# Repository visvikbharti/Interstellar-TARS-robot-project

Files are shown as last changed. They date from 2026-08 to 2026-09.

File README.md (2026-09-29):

# TARS — Mini Walking Robot (Interstellar)

A ~25–30cm, 3D-printed, walking and talking replica of TARS from *Interstellar*.
Raspberry Pi brain, servo-driven gait, Claude-powered personality with the
movie's adjustable **humor** and **honesty** settings.

> Cooper: "Hey TARS, what's your honesty parameter?"
> TARS: "Ninety percent."

## Project layout

```
software/    TARS's brain — personality, chat, (soon) voice + servo control
hardware/    Bill of materials, parametric CAD and its drawing, print plan (wiring doc to come)
docs/        Design decisions, research notes, India sourcing report
```

## Quick start (talk to TARS today, no hardware needed)

```sh
cd software
python3 -m venv .venv && source .venv/bin/activate
pip install -r requirements.txt
export ANTHROPIC_API_KEY=sk-ant-...   # or `ant auth login`
python -m tars.cli
```

Then chat:

```
You: /humor 100
TARS: Confirmed. Humor, 100 percent.
You: what are our odds of finishing this robot?
```

Without an API key it runs in offline mode with canned TARS quips, so you can
test the CLI immediately.

## Build status

- [x] Personality core (humor/honesty settings, Claude-powered chat, CLI)
- [x] Parametric CAD (`hardware/cad/tars.scad`, OpenSCAD, v0.3.1) and a dimensioned
      drawing read from it (`python hardware/drawing.py` -> `hardware/tars_drawing.png`)
- [x] Physics simulation — **it walks, robustly.** The build-target V3
      lift-and-swing gait, reworked into a crutch vault on 29 Sep 2026,
      walks 36 cm in 15 s (2.4 cm/s) at true MG996R torque and stays upright
      at every solver setting tested (`python v3_sim.py --robust`: time steps
      2 to 0.25 ms, three integrators, both friction cones, floor friction
      0.5-1.3, 20% weaker servos, body mass -10%/+20%). The IMU-balance walker
      and wheel mode do not work yet (`simulation/README.md`)
- [x] Research: proven community design identified (TARS-AI V3, 25.0cm,
      CC-BY-NC) — see `docs/research-notes.md`
- [ ] Parts ordered (`hardware/BOM.md`; prices live-verified 10 Aug 2026 — ready to order)
- [ ] Chassis printed (outsourced — `hardware/print-plan.md`)
- [ ] Voice: wake word → speech-to-text → TARS → text-to-speech
- [ ] Walking gait on real hardware
- [ ] Final assembly: it walks, it talks, it judges your plans

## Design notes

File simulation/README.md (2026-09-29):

# TARS simulations (MuJoCo)

Three models, all sharing dimensions with `hardware/cad/tars.scad`:

| Files | What it tests | Result (audited 2026-09-29) |
|---|---|---|
| `v3_model.py` + `v3_sim.py` | **The build architecture** (TARS-AI V3): central body touches ground, legs lift+swing. No balancing, no IMU | **walks 36 cm in 15 s (2.4 cm/s), upright**, with the crutch-vault gait, and the same at every setting in `--robust` |
| `gen_model.py` + `gait_sim.py` | v1 custom idea: 2 servo pairs + MPU6050 IMU balance ("lean and catch") | **does not walk upright**: slumps into a tilted A-frame within 0.5 s (0/75 sweep settings upright) |
| `pinwheel_model.py` + `roll_sim.py` | **Miller's planet WHEEL MODE**: 4 slabs splayed into a rimless wheel | **does not roll**: tumbles ~0.4 m, then folds flat or falls sideways; needs a different mechanism (telescoping spokes, TARS3D) -> v2 research |

```sh
source software/.venv/bin/activate    # from the project root
cd simulation
python v3_model.py && python v3_sim.py          # the build gait (headless)
python v3_sim.py --robust                       # the same gait across 15 solver/physics settings
mjpython v3_sim.py --gui                        # watch the V3 walk
python pinwheel_model.py && mjpython roll_sim.py --gui   # wheel mode (falls: v2 research)
mjpython gait_sim.py --gui                      # the IMU-balance walker (slumps)
```

Every sim has `--sweep` for parameter search and runs until you close the
window in `--gui` mode (auto-reset on falls, camera tracks the robot).
`v3_sim.py --sweep` only keeps gaits that stay upright at 2 ms AND at 0.5 ms
with elliptic friction cones. Every fall test checks the body and all slabs
(within 45 deg of vertical) and the axle height, not just the torso.
`/Applications/MuJoCo.app` opens any of the `tars*.xml` files interactively.

## Findings log

1. Open-loop wiggling on sharp-edged feet falls, always (300+ configs).
2. Rounded bottom edges (flat middle + 6mm round-over) let the robot roll
   over the stance foot; mass must sit LOW and CENTERED.
3. Two ways to walk: IMU balance loop (fewer servos, dynamic) or the V3
   lift+swing with ground-resting body (more servos, unconditionally stable).
   We build V3 first; the gait keyframes port straight to the Pi.
4. V3 gait: feet plant slightly AHEAD (the body vaults forward over them),
   small lift (30%), vault overlapped with lowering — a controlled forward
   topple. step=14deg back=4deg tempo=0.6 lift=0.3 -> 2.0cm/cycle.
5. Wheel mode physics: a 4-spoke rimless wheel cannot start from rest
   (90-degree tip-overs) — it must be THROWN in at >=1.6 m/s, and from a
   1.8 m/s entry coasts ~1.6m. Just like the movie. Powered rolling = v2
   research (telescoping spokes or 8+ spokes).
6. **Audit, 29 Sep 2026.** Re-running every sim with finer solver settings and
   stricter fall tests: (a) the old V3 gait (feet planted 14 deg ahead, vault
   overlapped with lowering) only walked at the default 2 ms time step; at
   0.5 ms, with the implicit integrator or with elliptic friction cones it
   tipped over within 3-9 s. Its progress came from the body rocking on its
   rails, not from a vault: the body landed before it vaulted. (b) The
   IMU-balance walker's "upright" came from a fall test that only checked the
   torso; its slabs slump to ~60 deg within 0.5 s. (c) Wheel mode's "~1.6 m"
   was the folded, flat robot creeping undriven after a ~0.4 m tumble.
7. **The fix: a crutch vault.** Press the legs down while they are VERTICAL
   (the weight stays over the feet), rotate the hinges back 12 deg with the
   body fully off the ground (it swings forward over the planted feet), set
   it down, then swing the unloaded legs forward. vault=12 lift=0.7
   tempo=1.0 -> 35.9 cm in 15 s (4.3 cm/cycle), worst tilt 11.5 deg, the same
   to within 2 mm at every time step from 2 ms to 0.25 ms. Peak swing torque
   0.30 N m (30% of an MG996R), peak lift force ~11 N (of 55 N).

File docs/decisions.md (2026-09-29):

# Design Decisions

## 1. Brain: Raspberry Pi 5, 8GB  (decided 2026-08-10)

The user owns NO Raspberry Pi; buying new in India (New Delhi).

**Choice: Raspberry Pi 5 — 8GB.** Rationale:
- The voice pipeline (wake word + on-device speech-to-text via sherpa-onnx +
  Piper text-to-speech) runs comfortably in real time on a Pi 5; on a Pi 4 the
  speech-to-text step is noticeably laggy for conversation.
- 8GB gives headroom to run STT + TTS + servo control + the Claude client
  simultaneously without swap. The 4GB saves ₹7,370 (live-verified 10 Aug 2026
  — India Pi pricing is steep, so the delta is real money), but on-device
  STT/TTS is exactly what eats RAM, and the only in-stock 4GB source is the
  vendor the BOM cautions against for large orders. 8GB stands.
- The community TARS-AI stack targets Pi 5, so we stay on the well-trodden path.
- The LLM itself is *not* local — TARS thinks via the Claude API — so we don't
  need anything bigger (no Jetson etc.).

Buy alongside it: official 27W USB-C PSU (bench use), the official Active
Cooler (the Pi 5 throttles without it), 64GB microSD (no India hobby vendor
stocks A2 — the BOM's SanDisk Ultra A1 is fine for a robot). On the robot, the
Pi runs from the battery through a 2S-rated 5V/5A converter instead of the PSU.
Exact INR prices + vendors: see `hardware/BOM.md` (live-verified 10 Aug 2026).

## 2. CAD: OpenSCAD  (user-suggested; agreed)

- Fully parametric — every dimension in `hardware/cad/tars.scad` is a variable;
  change `leg_h` once and the whole robot rescales.
- Text-based → diffs cleanly in git, and we can co-edit it easily.
- Exports STL directly for slicing AND meshes/dimensions shared with the
  simulator (`simulation/gen_model.py` / `v3_model.py` mirror the same
  numbers into MuJoCo MJCF).
- Escape hatch: if we later adopt proven community STLs (Charlie Diaz /
  TARS-AI, license research pending), OpenSCAD still handles our custom parts
  (spine, mounts, brackets).

## 3. Simulation: MuJoCo  (instead of Cinema 4D)

"Cinema 4D" is an animation/rendering tool — it makes pretty pictures but does
not simulate physics, motors, friction, or falling over, which is what we need
before printing. The plan:

| Purpose | Tool | Why |
|---|---|---|
| Gait physics (does it walk? fall?) | **MuJoCo** | DeepMind's physics engine, the robotics-research standard; installs instantly from a wheel; scriptable in Python; `mjpython gait_sim.py --gui` gives a live 3D view on the Mac |
| Mechanical fit / printability | **OpenSCAD** previews + slicer | Wall thickness, clearances, print orientation |
| Pretty renders (later, optional) | Blender (free) | Same niche as Cinema 4D, no license cost |

Alternatives considered: PyBullet (first pick, but it compiles from source on
macOS and the build failed — MuJoCo ships wheels and is the better engine
anyway), Webots (good fallback for sensor simulation), Gazebo (ROS-oriented,
overkill).

Big win: the balance gains and gait constants we tune in MuJoCo port almost
directly to the real servo code on the Pi.

## 4. Gait mechanism — VALIDATED IN SIM (2026-08-10)

> **Superseded by §8 (audit, 2026-09-29):** the IMU-balance result below did
> not hold up; the walker slumps into a tilted A-frame. Kept for the record.

Simulation verdict on the v0.1 two-servo rocking gait: **open-loop always falls**
(300+ configs swept). What made it walk:
- Deeper slabs (55mm), rounded bottom edges (roll-over, not edge-pivot)
- Low, centered mass: 18650 cells in outer slab bottoms, Pi on a front chest plate
- **IMU balance loop** (MPU6050): stance legs correct torso pitch, segway-style
- "Lean and catch": 0.04 rad forward lean + 25° kick gait at 1.2 Hz
- Result: **30cm in 10s (3.0 cm/s), upright, drift <1cm** at true MG996R
  torque (1.0 N·m; an earlier 5.1 cm/s figure came from an inflated 2.5 N·m
  servo model — corrected in the 10 Aug audit, all 75 sweep configs still
  stay upright)

## 5. Chassis fork: TARS-AI V3 STLs vs our custom SCAD

Research verdict: TARS-AI Community V3 is the ONLY proven walkable open design
(25.0cm tall — measured from their CAD; CC-BY-NC 4.0, personal use fine). Its
gait needs no balancing: 2 lift + 2 swing servos, torso rests on the ground
between steps.

**Recommended plan:** print & build TARS-AI V3 first (proven path: STLs,
assembly wiki, calibration tool, community Discord) while continuing our custom
OpenSCAD + MuJoCo design as the v2 platform (fewer servos, dynamic balance, our
own look). The electronics BOM is ~identical for both, so nothing ordered is
wasted either way. Next sim milestone: model the V3 lift+swing morphology in
MuJoCo and reproduce their keyframe gait before hardware arrives.

## 6. Sim-validated architecture + wheel mode (2026-08-10, late session)

> **Superseded by §8 (audit, 2026-09-29):** the V3 gait below only walked at
> the default 2 ms time step, and wheel mode did not roll. Kept for the record.

- **V3 morphology simulated and walking**: body-on-ground + lift/swing legs,
  2.4 cm/s quasi-static, zero falls (at true 1.0 N·m servo torque). Winning
  gait: plant feet 14deg AHEAD (step=14, back=4 — the body vaults forward
  over them), lift 30% of 35mm travel, vault overlapped with lowering
  (controlled forward topple). These keyframes ARE the future Pi servo code.
- **Wheel mode (Miller's planet)**: works as kickstart-and-coast — needs a
  ≥1.6 m/s entry; at 1.8 m/s (the sweet spot — 2.0 falls) the 4-slab
  pinwheel cartwheels ~1.6m. Cannot start from rest
  (4 spokes = 90deg tip-overs) and powered pumping destabilizes via hub
  counter-spin. Sustained powered rolling needs per-slab continuous drive +
  telescoping spokes (TARS3D, arXiv 2510.05001) -> v2 hardware goal with
  serial-bus servos.
- **CAD v0.3 final for v1**: central chassis (twin-slab facade; Pi vertical,
  display window, speaker grille, servo bays at the axle) + two outer legs
  (35mm axle slot for lift travel, 608ZZ bearing seat). v0.4 details pending:
  lift crank linkage, lids, wire channels.

## 7. Printing: outsourced to a print service (2026-08-10)

No home printer — chassis parts are ordered from an online 3D-printing
service, the workflow proven the same week on the micro-quad project
(ZBOTiC order delivered 10 Aug 2026; received part matched CAD, press-fit
bores true). Consequences:
- No filament spools in the BOM — material is specified in the print order
  instead (black PLA cosmetic, black PETG 3+ walls for load parts).
- No printer/bed-size constraint on our side.
- Vendors, settings, pinned STL source and on-receipt checks:
  `hardware/print-plan.md`.

## 8. Simulation audit + crutch-vault gait (2026-09-29)

Re-ran every simulation with finer solver settings (0.5 and 0.25 ms time
steps, the implicit and RK4 integrators, elliptic friction cones) and with a
strict fall test (body AND every slab within 45 deg of vertical, axle above
150 mm). Findings:

- **Old V3 gait** (feet planted 14 deg ahead, vault overlapped with lowering):
  walked only at the default 2 ms step; tipped over within 3-9 s at 0.5 ms,
  with implicitfast, or with elliptic cones. The body landed before it could
  vault; the progress came from rocking on the rails.
- **IMU-balance walker:** slumps into a tilted A-frame within 0.5 s (slabs
  ~60 deg, axle 140 mm). The old test only checked the torso.
- **Wheel mode:** tumbles ~0.4 m, then folds flat or falls sideways. Stiffer
  spokes (5-20 N m) fall sideways sooner. Needs a different mechanism (v2).

**Decision:** the build gait is now a **crutch vault**: press down on
vertical legs (weight over the feet), rotate the hinges back 12 deg with the
body fully off the ground, set down, swing the unloaded legs forward.
`vault=12 lift=0.7 tempo=1.0`: 35.9 cm in 15 s, worst tilt 11.5 deg, and the
same result at all 15 settings in `python v3_sim.py --robust` (incl. floor
friction 0.5-1.3, 20% weaker servos, body mass -10%/+20%). Peak loads: swing
0.30 N m (MG996R ~1.0), lift ~11 N (of 55). These keyframes are the future
Pi servo code. The CAD needs no change (the gait uses 24.5 of the 35 mm lift
travel).

## 9. CAD v0.3.1: the lift slot moves to the body (2026-09-29)

Drawing the chassis up (`hardware/drawing.py`) and cutting sections through
`tars.scad` turned up four problems in v0.3, all fixed in v0.3.1:

- **The lift could not work.** The 35 mm slot was in the legs with the axle at
  its top at rest, so a leg could only rise relative to the axle, never press
  down (the gait needs the legs to push the body up). The slot is now in the
  body: at rest the body sits on the ground with the axle at the top of the
  slot, and pressing the legs down raises the body up to 35 mm. This is the
  relative motion `v3_model.py` already simulates, so the gait results stand.
  Legs keep a round axle bore and a round 608ZZ seat (the swing).
- **The right leg was not mirrored**, so its bearing seat faced outwards. Both
  seats now face the body (`print_leg_right` prints the mirrored leg).
- **The left servo bay sat in the middle of the body** (its offset ignored the
  side). The bays are now mirror images, one against each inner wall.
- **The face panels were turned 90 deg and half a panel low**, so they
  overlapped and ran off the legs. They are now the 3 rows of
  (h - 40)/3 - 6 by w - 12 the formula describes.

The drawing reads every dimension from `tars.scad`, so it cannot drift from
the model.

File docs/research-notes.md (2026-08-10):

# Research Notes — TARS builds landscape (2026-08-10)

Digest of a 10-agent research sweep (5 topics + critic + 4 follow-ups), all
claims verified on fetched pages. Full raw report archived in the session.

## The one proven base: TARS-AI Community V3

- **github.com/TARS-AI-Community/TARS-AI** — 574★, active (last push Apr 2026),
  the de-facto continuation of Charlie Diaz's original design. Default branch
  is **V3** (do NOT use `main` — it carries obsolete V1/V2 tooling).
- **Exactly 25.0cm tall** (an agent downloaded their official STEP assembly and
  measured it: 241.8 × 250.1 × 65.4 mm). Print at 100% — do not rescale, every
  fit is dimensioned around COTS parts.
- ~130 pre-oriented STLs, full BOM, assembly wiki. License **CC-BY-NC 4.0**:
  personal building/modifying is explicitly fine (attribution: Charlie Diaz /
  TARS-AI Community / AtomikSpace); selling prints is not.
- Survey verdict: **no alternative walkable STL set exists anywhere** —
  everything else is static display models, closed research (TARS3D), or
  software stacks reusing this same chassis.

## How the proven design walks (important!)

V3 uses **4 servos**: left/right torso-LIFT + left/right leg-SWING. The gait
never balances — it lifts the torso, swings legs, and **rests the torso on the
ground** while repositioning. Quasi-static keyframe tables (percent coords in
`module_movements.py`), tuned via config.ini PWM endpoints + offsets.
Calibration: official video "Getting TARS Moving Right" (youtube We_4mcOO7hI)
by the V3 hardware author + `app-servotester.py` (GUI/terminal). Calibrate
DURING assembly (preset servos before pressing horns on, never rotate a powered
servo by hand). Our MuJoCo sim independently confirmed *why* the lift DOF
exists: without it, an open-loop 2-servo gait always tips over — we made
2-servo walking work only by adding an IMU balance loop.

## Voice stack (2026 state of the art on Pi)

| Layer | Choice | Notes |
|---|---|---|
| Wake word | openWakeWord, custom "Hey TARS" (or TARS-AI's Atomik) | Train free in Colab from synthetic speech, <1h |
| STT | sherpa-onnx (TARS-AI default) or Moonshine (MIT, 237ms on Pi 5) | Fully local on Pi 5 |
| TTS | Piper (local, free; now OHF-Voice/piper1-gpl) | ElevenLabs voice-clone of the movie voice is the community method for authenticity (~$6/mo; ToS caveat — cloning an actor's voice) |
| LLM | **Claude API** (our personality core) | Precedent: "Claudia" project runs Claude on a Pi Zero 2 W, <2s end-to-end. TARS-AI's backends are OpenAI-compatible → we write a thin adapter or our own ~200-line loop |

**The latency law**: stream the LLM reply and speak sentence-by-sentence
(start TTS after the first sentence). This is what turns 8–15s perceived
latency into ~2s. Design target: wake→speech ≈ 1.5–4s.

## Pi 4 vs Pi 5 (contradiction resolved by reading their code)

The wiki documents only Pi 5, but `Install.sh` + `module_config.py` on V3 have
a first-class **Pi 4 profile** (local STT/TTS/wake word all allowed; loses
camera vision, face/emotion, half the STT threads, 8k vs 16k context). Pi 3 /
Zero 2 = cloud-only mode. → For a new purchase, Pi 5 8GB is the clear choice.

## Audio amp question (resolved for stock V3 — our BOM deviates)

The **TARS-AI V3 stock BOM's** Waveshare USB audio dongle has an **onboard
2.6W amplifier** driving the speaker directly — if you build stock V3 audio,
no MAX98357A is needed (if quiet: internal trim screw + alsamixer). **Our**
`hardware/BOM.md` instead buys the I2S pair (INMP441 mic + MAX98357A amp):
better audio quality and no USB dongle, but it deviates from the stock V3
software path and needs I2S dtoverlay config on the Pi. Both paths work —
just know which one you're wiring.

## Key pitfalls from the Diaz lineage

- Diaz's V1 broke printed drivetrain parts after ~4 steps — heavy batteries +
  torso-heavy mass. Keep mass low and light; PETG 3+ walls on load parts.
- Route arm servo cables through the torso during initial assembly even if
  arms come later (otherwise: full disassembly).
- Gentler gait = pull in the lift endpoints in config.ini, not new phase tables.
- Support runs on Discord (discord.gg/AmE2Gv9EUt); GitHub issues are locked.

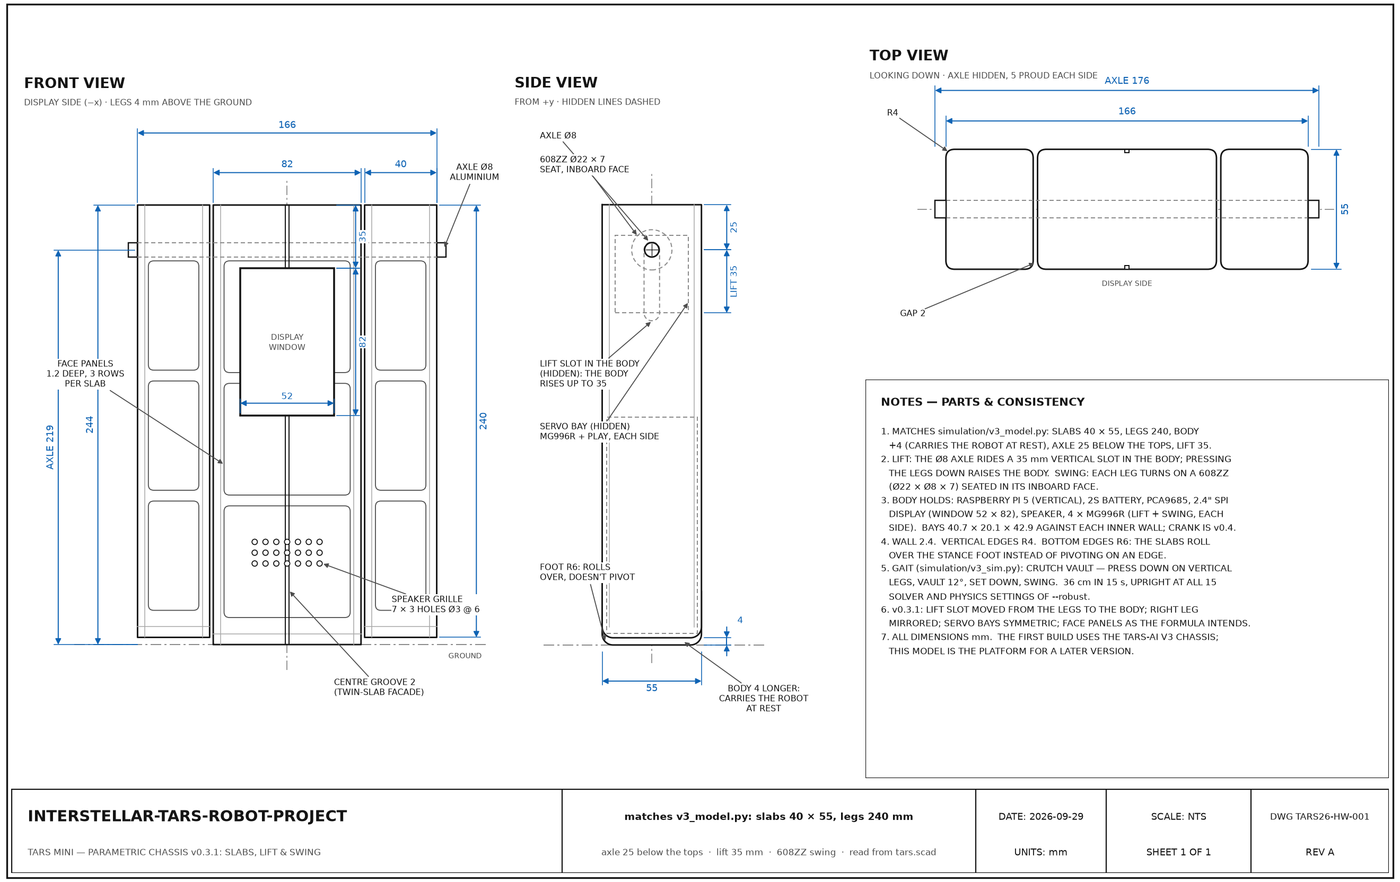
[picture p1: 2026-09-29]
hardware/tars_drawing.png

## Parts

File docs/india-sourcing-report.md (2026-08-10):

# Robot Parts Sourcing — India (New Delhi buyer), August 2026

**Method note:** every price below was pulled from the vendor's own live storefront data (robu.in product/listing pages rendered through a reader proxy; Shopify storefront product API for Robocraze / ThinkRobotics / KitsGuru / The Engineer Store), not from search snippets. robu.in prices are the "(Incl. GST)" figure shown on the page. Shopify vendors display final cart price. Prices verified 10 Aug 2026.

## Master table

| Item | Spec | Price (INR) | Vendor + URL | Notes (stock / alternatives) |
|---|---|---|---|---|
| **Raspberry Pi 5 8GB** | BCM2712, 8GB | **19,999** | [robu.in](https://robu.in/product/raspberry-pi-5-model-8gb/) SKU 1749034 | **In Stock.** Best reliable price. |
| Pi 5 8GB (alt) | same | 19,849.99 | [ThinkRobotics](https://thinkrobotics.com/products/raspberry-pi-5) | In stock (8GB variant). Effectively tied with robu. |
| Pi 5 8GB (alt) | same | 22,339 | [Robocraze](https://robocraze.com/products/raspberry-pi-5-8gb) | In stock but ~₹2,340 more. |
| Pi 5 8GB (cheapest, **caution**) | same | 17,967 | [The Engineer Store](https://www.theengineerstore.in/products/raspberry-pi-5-8gb) | Listed "52% off ₹37,100" (inflated MRP) and page warns *"Quantity selected exceeds current stock"*. Verify before relying on it. |
| **Pi 5 4GB** | BCM2712, 4GB | 12,631 | [The Engineer Store](https://www.theengineerstore.in/products/raspberry-pi-5-4gb) | Available. ThinkRobotics 4GB = ₹13,609.99 but **out of stock**. |
| Pi 5 2GB | budget path | 7,799.99 | [ThinkRobotics](https://thinkrobotics.com/products/raspberry-pi-5) | In stock — this is the "₹7-8k Pi 5" you see quoted online; it is the 2GB, not 8GB. |
| **Official 27W USB-C PD PSU** | 5.1V/5A, **IN plug**, black or white | **1,255** | [robu.in black](https://robu.in/product/official-27w-usb-c-pd-power-supply-for-raspberry-pi-5-black/) / [white](https://robu.in/product/official-27w-usb-c-pd-power-supply-for-raspberry-pi-5-white/) | **In Stock**, both colours. Robocraze ₹1,204 but **out of stock**; ThinkRobotics ₹1,479.99 **out of stock**; Engineer Store ₹1,649.89 available. |
| **Official Pi 5 Active Cooler** | clip-on PWM fan+heatsink | **488** | [robu.in](https://robu.in/product/official-raspberry-pi-5-active-cooler/) SKU 1749017 | **In Stock**, cheapest. Robocraze ₹529 out of stock; Engineer Store ₹551.52; Waveshare clone ₹689 out of stock. |
| **64GB microSD** | SanDisk Ultra microSDXC UHS-I, 140MB/s, **A1** | **1,536** | [Robocraze](https://robocraze.com/products/sandisk-64gb-micro-sd-sdhc-card) | In stock. robu.in same card ₹1,859 in stock. **No vendor here stocks an A2 card** — see gaps. |
| **MG996R servo, 180°** | ~10-11 kg·cm metal gear | **292** | [Robocraze](https://robocraze.com/products/mg996r-servo-motor) | In stock, explicitly "180 Degree". **Cheapest correct part.** |
| MG996R 180° (alt) | same | 343 | [The Engineer Store](https://www.theengineerstore.in/products/mg996r-servo-motor-180-degree) | In stock. |
| ⚠️ MG996R at robu.in | **continuous 360°** | 343 | [robu.in](https://robu.in/product/towerpro-mg996r-digital-high-torque-servo-motor/) SKU 618530 | In Stock but page states *"Continuous 360 degree rotation motor"* — **wrong for joints.** robu's other MG996R (SKU 1070680, ₹406) does not state rotation; an unanswered customer question about it is still on the page. Don't buy MG996R from robu without confirming. |
| MG996R 4-pack | 4× 180° | ~1,749–3,989 | [Amazon.in listings](https://www.amazon.in/MG996R-Analog-Digital-Helicopter-Project/dp/B0F2TKPB95) | No specialist vendor sells multipacks. The ₹1,749 REES52 pack is the **360°** version. 6× singles at Robocraze = ₹1,752 — same money, correct part. |
| **DS3218 20kg servo** | 20 kg·cm digital, 180° | **2,099.99** | [ThinkRobotics](https://thinkrobotics.com/products/ds3218-servo) | **In stock — the only reliable source.** |
| DS3218 at robu.in | 180° / Pro | 1,441 / 1,582 | [robu 180°](https://robu.in/product/pro-range-ds3218-20kgcm-digital-servo-motor/) / [robu Pro](https://robu.in/product/pro-range-ds3218-pro-20kgcm-metal-gear-digital-servo-motor-180-degree/) | **Both Out of Stock.** Cheapest if they restock. |
| DS3218 (alt) | Pro 180° | 4,150 incl GST | [Probots](https://probots.co.in/servo-ds3218-pro-20kg-180-degrees-high-torque-high-speed-digital-steering-gear.html) | In stock but ~2× the ThinkRobotics price. |
| **LX-16A serial bus servo** | Hiwonder, 17kg, feedback, 240° | **2,099.99** | [ThinkRobotics](https://thinkrobotics.com/products/hiwonder-lx-16a-full-metal-gear-serial-bus-servo-with-real-time-feedback-function-for-rc-robot-control-angle-240) | In stock. Only Indian source found. |
| Bus servo (alt) | Waveshare SC15, 17kg | 1,957.82 | [The Engineer Store](https://www.theengineerstore.in/products/waveshare-sc15-17kg-large-torque-programmable-serial-bus-servo) | In stock, cheaper than LX-16A. ST3215 at ThinkRobotics ₹2,399.99. |
| **PCA9685 16-ch PWM driver** | I2C, 12-bit, soldered headers | **232** | [Robocraze](https://robocraze.com/products/pca9685-16-channel-servo-motor-driversoldered) | **In stock.** |
| PCA9685 at robu.in | — | 210 / 369 | [robu.in](https://robu.in/product/16-channel-12-bit-pwmservo-driver-i2c-interface-pca9685-arduino-raspberry-pi/) | **Both Out of Stock.** |
| PCA9685 (alt) | Waveshare Servo Driver **HAT (B)** | 1,207 | [robu.in](https://robu.in/product/waveshare-servo-driver-hat-b-for-raspberry-pi-16-channel-12-bit-i2c/) | In Stock. Pi-native, stacks on GPIO, integrated servo power input — cleaner for this build. |
| **2S 7.4V 3500mAh pack (recommended)** | Molicel M35A, 2S1P, pre-built | **999** | [robu.in](https://robu.in/product/molicel-a-grade-inr-18650-m35a-7-4v-3500mah-3c-2s1p-tx-li-ion-battery-pack/) SKU R149972 | **In Stock.** Genuine A-grade cells, tabbed + wired. Skips DIY pack assembly. |
| 2S pack (alt) | Samsung 35E 2S1P 3500mAh | 899 | [robu.in](https://robu.in/product/samsung-inr18650-35e-7-4v-3500mah-2c-2s1p-li-ion-battery-pack/) SKU 1366608 | In Stock. BAK NMC 3500mAh ₹799 also in stock. |
| **18650 loose cell** | Murata (Sony) VTC6 3000mAh, 7C | **691** | [robu.in](https://robu.in/product/sony-vtc6-18650-li-ion-3000-mah-battery/) SKU 63449 | **In Stock.** High discharge — good for servo surges. |
| 18650 loose (alt) | Panasonic NCR18650GA 3300mAh | 635 | [robu.in](https://robu.in/product/panasonic-ncr18650ga-3300mah-3c-li-ion-battery/) SKU 623975 | In Stock. Samsung 30Q (₹578) and LG MJ1 (₹392) both **out of stock**. |
| **2S cell holder** | 2×18650 | 21 | [Robocraze](https://robocraze.com/products/18650-2-cell-holder) | In stock. Engineer Store ₹20.99–30.43; ThinkRobotics ₹52.99. |
| **2S BMS** | 2S **8A cont.** (10A burst), 7.4–8.4V | **69** | [robu.in](https://robu.in/product/2s-8a-18650-7-4v-8-4v-lithium-battery-protection-board/) SKU 600732 | In Stock. Page-verified 8A max — marginal for Pi + servo surges through one BMS; prefer a 15–20A 2S BMS (see BOM). HX-2S-A2 ₹56 and 2S 5A ₹59 also in stock. |
| TP4056 module | 1S only, USB-C, w/ protection | 15–16 | [KitsGuru](https://kitsguru.com/products/tp4056-1a-li-ion-battery-charging-board-micro-usb-with-current-protection-1) / [Robocraze](https://robocraze.com/products/tp4056-battery-charger-c-type-module-with-protection-1) | In stock. ⚠️ **TP4056 cannot charge a 2S pack** — see gaps. |
| **LM2596 buck module** | adjustable step-down | **42** | [robu.in](https://robu.in/product/lm2596s-dc-dc-buck-converter-power-supply/) SKU 11548 | In Stock. ⚠️ **3A max — NOT for the servo rail** (six MG996R ≈ 15A stall); the BOM now uses an 8A 2S UBEC (₹1,579) instead. KitsGuru ₹44, Robocraze ₹48, Engineer Store ₹62–70. |
| **5V/5A step-down (Pi rail)** | 24/12/9V→5V 5A, 25W | **189** | [robu.in](https://robu.in/product/dc-dc-step-down-buck-converter-power-supply-module-24v-12v-9v-to-5v-5a-25w-replace-lm2596s/) SKU 395957 | **In Stock.** ⚠️ Page-verified input **9–24V** — a 2S pack (6.4–8.4V) never reaches its minimum; unusable for this build. Superseded in the BOM by the UBEC 5V/5A (SKU 974872, ₹392, input 5.5–35V). |
| 5V/5A (compact alt) | MINI560, 5V 5A | 91 | [robu.in](https://robu.in/product/mini560-dc-5v-5a-step-down-stabilized-module/) SKU 1121356 | In Stock. KitsGuru ₹89, Robocraze XY-3606 ₹129. Tiny, but 5A is the *ceiling* — run the Pi only, never servos. |
| **INMP441 I2S MEMS mic** | omnidirectional, I2S | **136** | [Robocraze](https://robocraze.com/products/inmp441-mems-high-precision-omnidirectional-microphone-module-i2s) | In stock. robu.in ₹146 In Stock (SKU 975775); KitsGuru ₹189; Engineer Store ₹239.56. |
| **MAX98357A I2S amp** | 3W Class-D, DFRobot | **531.06** | [The Engineer Store](https://www.theengineerstore.in/products/dfrobot-max98357-i2s-amplifier-module) | In stock. robu.in DFRobot ₹669 In Stock; Adafruit version ₹730 (robu) / ₹732.48 (Engineer Store). |
| ⚠️ MAX98357A generic | cheap breakout | 177–269 | [robu.in](https://robu.in/product/bgamax98357a-i2s-amplifier-breakout-module/) | **All four generic variants Out of Stock at robu.in.** Robokits lists one at ₹89. |
| **Speaker 4Ω 3W** | 40×70mm | **263.94** | [The Engineer Store](https://www.theengineerstore.in/products/speaker-4-ohm-3w-size-4070) | In stock. Makerfabs 4Ω 3W ₹440.96; Adafruit 3351 ₹450.50. robu.in stocks only 8Ω 0.5W (₹52–120). |
| **USB mini mic** (alternative to I2S) | plug-and-play UVC | **201.72** | [The Engineer Store](https://www.theengineerstore.in/products/usb-microphone-for-raspberry-pi-color-may-vary) | In stock. robu.in equivalent ₹176 **out of stock**. |
| **2" / 2.4" SPI TFT (face)** | ST7789V, 240×320, 10-pin SPI | **427** | [robu.in](https://robu.in/product/goldenmorning-st7789v-10p-240x320-spi-2-4-inch-tft-display/) SKU R123203 | **In Stock.** Best price/spec for the face display. |
| 2.4" SPI TFT (alt) | ILI9341 240×320 | 629 | [robu.in](https://robu.in/product/2-4-inch-spi-interface-240x320-touch-screen-tft-display-module/) SKU 766311 | In Stock. Engineer Store ₹636.14; KitsGuru 2.8" no-touch ₹519. |
| **Small HDMI option** | Waveshare 3.5" HDMI 480×320 | 3,099 | [robu.in](https://robu.in/product/waveshare-3-5-inch-resistive-hdmi-lcd-display-480x320/) | In Stock. 5" HDMI 800×480 ₹2,470 (robu, In Stock) / ₹2,344 (Robocraze). HDMI costs 6–7× the SPI panel — SPI is the right call for a 25cm robot. |
| **M3 bolts + nuts** | M3×12, 12 pcs | 71 | [robu.in](https://robu.in/product/easymech-set-of-m3-x-12mm-socket-bolt-and-nut-set/) | In Stock. M3×30 12pcs ₹175. Engineer Store "Orange 200pcs robot screw kit" ₹1,050.60. |
| **608ZZ bearings** | 8×22×7mm | **16 ea** | [robu.in](https://robu.in/product/miniature-bearings-608zz/) SKU R185207 | **In Stock**, cheapest by far. robu 4-pack ₹62; Engineer Store ₹26.82 ea / 4-pack ₹82.47; Robocraze ₹39 ea / 4-pack ₹135. |
| **8mm aluminium tube** | 8mm OD / 3mm ID / 300mm | **249.99** | [ThinkRobotics](https://thinkrobotics.com/products/diy-aluminium-tubes) | In stock (8mm/3mm/300mm variant). 8mm/2mm/300mm and 8mm/3mm/1000mm are out of stock. |
| **PLA filament 1kg** | Sunlu PLA+ 1.75mm | **939** | [robu.in](https://robu.in/product/sunlu-pla-gold-1-75mm-1kg-roll-filament/) | In Stock (gold/beige/fuchsia/pink at ₹939). **Black is ₹1,398** — Sunlu prices vary sharply by colour. |
| PLA (alt) | generic 1.75mm, many colours | 1,015.82 | [The Engineer Store](https://www.theengineerstore.in/products/1-75mm-white-pla-filament-1kg) | In stock. Robocraze eSUN PLA+ black ₹1,299; eSUN silk ₹1,386–1,456. |

---

## (a) Estimated total — single robot, Pi 5 8GB path

Assumes a 6-servo walker with MG996R class joints, I2S audio, a 2.4" SPI face panel, and one spool of filament.

| Group | Items | Subtotal (INR) |
|---|---|---|
| Compute | Pi 5 8GB 19,999 + 27W PSU 1,255 + Active Cooler 488 | 21,742 |
| Storage | SanDisk 64GB 1,536 | 1,536 |
| Motion | 6× MG996R 180° @292 = 1,752 + PCA9685 232 | 1,984 |
| Power | Molicel 2S pack 999 + 2S BMS 69 + 5V/5A buck 189 + LM2596 42 | 1,299 |
| Audio | INMP441 146 + MAX98357A 531 + 4Ω 3W speaker 264 | 941 |
| Display | 2.4" ST7789 SPI 427 | 427 |
| Mechanical | 608ZZ ×4 62 + M3 sets 246 + 8mm alu tube 250 + PLA 1kg 939 | 1,497 |
| **Total** | | **≈ ₹29,430** |

Add roughly **₹500–800** for hookup wire, JST/Dupont connectors, a power switch and shipping on the smaller orders → budget **₹30,000–30,500** all-in.

> **Post-audit correction (10 Aug, late):** the Power group above is wrong — the ₹189 buck can't take 2S input and the LM2596 can't feed six servos — and this estimate omits the 2S charger, a big-enough BMS, and the speaker. Filament also dropped out: printing is outsourced to a service (`hardware/print-plan.md`). The corrected buy plan in `hardware/BOM.md` lands at **≈ ₹31,450–31,750 electronics all-in, plus the 3D-printing quote**.

Useful swings on that number:
- **Pi 5 4GB instead of 8GB:** −₹7,370 (→ ~₹22,100). But this build's pipeline *is* on-device speech models (sherpa-onnx STT + Piper TTS), so by that criterion 8GB is the right buy — and the only in-stock 4GB source is The Engineer Store (see the caution at the end).
- **DS3218 20kg instead of MG996R** (6×): +₹10,848 (→ ~₹40,300). Only worth it if the legs actually need 20 kg·cm; for a 25–30cm TARS, MG996R is usually sufficient and DS3218 is out of stock at the cheap vendor anyway.
- **LX-16A serial bus servos** (6×): +₹10,848, and you'd drop the PCA9685 (−₹232). Big win in wiring simplicity and position feedback, big hit to budget.
- **Skip the SPI screen, use USB mic instead of I2S:** −₹371 (screen −427, INMP441 −146, USB mic +202).

## (b) Hard to get in India — and what to use instead

1. **A2-class 64GB microSD.** Every hobby vendor stocks the SanDisk **Ultra**, which is **A1**, not A2. → Buy a SanDisk **Extreme** A2 on Amazon.in (~₹1,800–2,200), or just accept A1 — for a robot that boots and runs Python it makes almost no practical difference.
2. **Cheap MAX98357A breakout.** All four generic variants are **out of stock at robu.in**; only DFRobot (₹531–669) and Adafruit (₹730) branded boards are available, 3–6× the usual price. → Robokits lists a generic at ₹89 (worth a stock check), or drop I2S entirely and use a **PAM8403 amp (₹29, Robocraze)** with a USB audio dongle.
3. **DS3218 20kg servos.** Out of stock at robu.in (both variants, the cheapest source). → **ThinkRobotics ₹2,099.99** is the only sane in-stock option; Probots at ₹4,150 is not worth it.
4. **LX-16A serial bus servos.** Single source (ThinkRobotics, ₹2,099.99). → **Waveshare SC15 17kg at ₹1,957.82** (Engineer Store) or **ST3215 at ₹2,399.99** are equivalent-class bus servos with better availability.
5. **Genuine Samsung/LG 18650 cells.** Samsung 30Q (₹578) and LG MJ1 (₹392) are both **out of stock** at robu.in. → **Murata/Sony VTC6 ₹691** or **Panasonic NCR18650GA ₹635**, both in stock. Better still, buy the **pre-built 2S packs** (Molicel ₹999 / Samsung 35E ₹899 / BAK ₹799) — genuine cells, already tabbed and wired, and it removes the spot-welding problem entirely.
6. **8mm aluminium rod/tube.** Hobby vendors barely stock raw stock; only the ThinkRobotics 300mm variant is available. → For a Delhi buyer this is the one item to buy **offline**: Lajpat Rai Market / Bhagirath Palace (Chandni Chowk) hardware stalls sell aluminium rod by the foot for a fraction of the online price.
7. **M3 screw/nut assortment kit.** Nobody sells a good cheap assortment — robu sells per-size 12-piece sets (₹71–175 each), and the Engineer Store's 200-piece kit is ₹1,050.60. → An Amazon.in M3 assortment box (~₹400–600) is better value, or buy loose from Lajpat Rai Market.

**Two design gotchas worth flagging before you order:**

- **TP4056 cannot charge your 2S pack.** It is a 1S (4.2V) charger. For a 7.4V pack you need an **8.4V CC/CV adapter feeding the 2S BMS**, or a dedicated 2S charger. Buying a TP4056 for this build is a dead end.
- **Don't run servos off the 5V/5A buck.** Six MG996Rs can stall at ~2.5A each. A 5A module is sized for the Pi alone. Give the servos their **own** high-current rail — a 6V UBEC of 8A+ — with a fat electrolytic across the servo rail. (Post-audit correction: the ₹189 module first suggested for the Pi rail turned out to be 9–24V-input and can't run from 2S at all; the corrected two-UBEC chain is in `hardware/BOM.md`.)

## (c) Vendor consolidation for a Delhi buyer

**Anchor on robu.in (Pune).** It carries ~₹24,900 of this BOM in stock — the Pi, PSU, cooler, battery pack, BMS, both buck converters, the INMP441, the SPI display, bearings, M3 hardware and filament. Free shipping over ₹999 (well clear), ships within 24h via FedEx/Aramex, 2–5 working days to Delhi. It also has the most trustworthy stock data of any vendor here — it shows real per-SKU In Stock / Out of Stock, which is why it caught the PCA9685 and DS3218 shortages.

**Add Robocraze (Bangalore) as the second order** — ₹3,520 for the three things robu can't do: the **PCA9685** (out of stock at robu), the **correct 180° MG996R** (robu's is continuous-rotation), and the microSD (₹323 cheaper). Free delivery over ₹999, COD over ₹500.

Those two cover about 96% of the build. To avoid a third and fourth parcel:

- Buy the **DFRobot MAX98357 from robu at ₹669** instead of Engineer Store at ₹531 — costs ₹138 more, saves a separate shipment.
- Take robu's **8Ω speaker at ₹120** instead of the 4Ω from Engineer Store, or source a speaker locally.
- Get the **8mm aluminium tube offline in Delhi** rather than a ₹250 item shipped from ThinkRobotics.

That collapses the build to a clean **two-vendor buy: robu.in + Robocraze**, roughly ₹25,700 + ₹3,520.

**A caution on The Engineer Store.** Its prices are frequently the lowest in the table (Pi 5 8GB at ₹17,967, DFRobot amp at ₹531), but the Pi 5 listing shows an inflated "₹37,100 → 52% off" MRP and the page itself warns *"Quantity selected exceeds current stock."* I also could not find any "tax included" labelling on their product pages, and their odd price decimals (₹441.91, ₹1,649.89) are consistent with a pre-GST or formula-derived figure. Confirm the landed, GST-inclusive price and real stock before committing a ₹18,000 order there. For the ₹800 of small parts, the risk is negligible.

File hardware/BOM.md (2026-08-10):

# Bill of Materials — TARS mini (India edition)

Prices live-verified on Indian vendor storefronts on **10 Aug 2026** (robu.in
GST-inclusive page prices; Shopify cart prices for Robocraze/ThinkRobotics).
Based on the proven TARS-AI V3 electronics architecture + our additions.

**Revised 10 Aug 2026 (late), after a full pre-order audit:** the original
power chain would not have worked — the LM2596 (3A) servo rail and the
9–24V-input Pi buck are replaced with page-verified 2S-input UBECs, and the
missing 2S charger, 20A BMS and speaker are now line items. Filament spools
were then removed again: printing is outsourced to a service (see
`print-plan.md`), which supplies the material.

## The buy plan (three orders; robu.in carries ~88%)

**Order 1 — robu.in** (Pune; free shipping >₹999; 2–5 days to Delhi, reliable
per-SKU stock data):

| Item | Spec | ₹ (incl. GST) | Notes |
|---|---|---|---|
| Raspberry Pi 5 — 8GB | the brain | **19,999** | 4GB budget path: see Totals table below |
| Official 27W USB-C PSU (IN plug) | bench power | 1,255 | |
| Official Pi 5 Active Cooler | mandatory in closed torso | 488 | |
| Molicel 2S 7.4V 3500mAh pack | pre-built, A-grade, tabbed+wired | 999 | Skips DIY 18650 spot-welding entirely (Samsung 35E ₹899 alt) |
| UBEC-8A 2–8S Lipo | battery → **servo rail** (set **6.0V**) | 1,579 | 8A cont / 15A burst, input 6–36V ([robu](https://robu.in/product/ubec-8a-6-36v-28s-lipo-esc/)). The ONLY in-stock 2S-input unit ≥8A anywhere on 10 Aug. Add 470–1000µF cap across the rail. 6.0V (not 7.4V) keeps stall current down; if you later want sustained-stall margin, add a second and split 3 servos per UBEC |
| UBEC 5V/5A | battery → **Pi rail** | 392 | Input 5.5–35V, covers 2S sag ([robu SKU 974872](https://robu.in/product/ubec-5v-5a/)). Page says 5.25V±0.5 out — **measure under load before first connecting the Pi**; feed the GPIO 5V pins or a 5A USB-C pigtail; expect the Pi's low-power-supply warning (`usb_max_current_enable=1`). ₹91 MINI560 is an in-stock hedge but has only 0.4V margin at pack floor |
| 2S charger, 8.4V/2A CC/CV | charges the pack through its BMS | 534 | Pro-Range ETC20, barrel plug ([robu](https://robu.in/product/pro-range-battery-charger-2s-li-ion-8-4v-2a-with-dc-5-5mm-2-5mm-male-plug/)). 5.5×2.5mm MALE plug — solder a female barrel pigtail onto the pack's charge leads |
| INMP441 I2S MEMS mic | ears | 146 | |
| DFRobot MAX98357A I2S amp | voice amp | 669 | ₹138 more than Engineer Store, saves a third parcel |
| 2.4" ST7789V SPI display 240×320 | face/status | 427 | (V3 stock design uses a 5" screen — see below) |
| 608ZZ bearings ×4 | axle | 62 | |
| M3 bolt+nut sets | assembly | ~250 | Better: M3 assortment box on Amazon.in (~₹400–600) or Lajpat Rai Market |
| MPU6050 IMU | balance loop (our addition) | ~150 | |
| **Subtotal** | | **≈ ₹26,950** | |

> **No filament in this order.** Printing is outsourced to a 3D-printing
> service (no home printer) — spec black PLA for cosmetic parts and black
> PETG for load parts in the print order instead of buying spools. Vendors,
> settings and the STL source are in `print-plan.md`; budget is a quote at
> upload time (service minimums + per-gram rates dominate).

**Order 2 — Robocraze** (Bangalore; free delivery >₹999):

| Item | Spec | ₹ | Notes |
|---|---|---|---|
| MG996R servo **180°** ×4–6 | leg joints | 292 each | ⚠️ **robu.in's MG996R is the 360° continuous version — wrong for joints. Buy here.** |
| PCA9685 16-ch servo driver | I2C, soldered | 232 | Out of stock at robu |
| SanDisk Ultra 64GB microSD | A1 | 1,536 | A2 cards absent from hobby vendors; A1 is fine for a robot (or SanDisk Extreme A2 on Amazon.in ~₹2k) |
| **Subtotal (6 servos)** | | **≈ ₹3,520** | |

**Order 3 — ThinkRobotics** (the two parts neither robu nor Robocraze stocks
in the right rating — both page-verified in stock 10 Aug, "only a few left"):

| Item | Spec | ₹ | Notes |
|---|---|---|---|
| BMS 2S **20A** | pack protection, 20A cont discharge / 10A charge | 170 | robu's in-stock 2S boards top out at 8A — a multi-servo stall would cut power to everything incl. the Pi (SD-corruption risk). [Product](https://thinkrobotics.com/products/bms-liion-lipo-battery-charger-protection-board) (pick the 2S 20A variant). Cheaper alt if it restocks: Robocraze's ₹65 2S-20A balanced board |
| 2030 cavity speaker 8Ω 2W | voice output — MAX98357A puts ~1.8W into 8Ω | 300 | 20×30×5.5mm, PH1.25 plug (re-terminate). [Product](https://thinkrobotics.com/products/2030-cavity-speaker-8%CF%89-2w). The ideal 4Ω 3W at Robocraze (₹124) is sold out |
| **Subtotal** | | **≈ ₹470** + shipping | |

**Buy offline in Delhi:** 8mm aluminium rod/tube — Lajpat Rai Market /
Bhagirath Palace (Chandni Chowk), by the foot, cheaper than any online option
(ThinkRobotics has 300mm at ₹250 if you'd rather not go).

## Totals

| Build | Total |
|---|---|
| **Pi 5 8GB path (recommended)** | **≈ ₹31,450–31,750** electronics all-in (₹26,950 robu + ₹3,520 Robocraze + ~₹470 ThinkRobotics + ₹500–800 wire/connectors/switch) **+ the 3D-printing service quote** (`print-plan.md`). +₹3,216 if swapping to the 5" DSI panel (see display note) |
| Pi 5 **4GB** path | ≈ ₹24,100 (−₹7,370) — but the only in-stock 4GB (₹12,631) is at The Engineer Store, the vendor trap #4 says to verify first; and 4GB squeezes the on-device STT/TTS headroom this build depends on |
| DS3218 20kg servo upgrade ×6 | +₹10,850 (ThinkRobotics ₹2,099 ea — the only in-stock source; robu cheaper but out of stock) |

The Pi is ⅔ of the budget — India's Pi 5 8GB price (~₹20k across vendors) is
much steeper than US pricing. If the total stings, the 4GB is the honest
budget lever, not cheaper servos.

## Traps the research caught (read before ordering!)

1. **robu.in's MG996R is continuous-rotation (360°)** — useless for position
   joints. Buy the explicit "180 Degree" one from Robocraze.
2. **TP4056 chargers cannot charge a 2S pack** (1S only). Charge the 7.4V pack
   through the BMS with an 8.4V CC/CV adapter or a dedicated 2S charger.
3. **Never run servos from the Pi's 5V buck** — 6× MG996R stall at ~2.5A each.
   Separate rails, shared ground only.
4. **The Engineer Store** has the lowest sticker prices (Pi 5 8GB ₹17,967) but
   inflated-MRP discounts, a stock warning on the Pi listing, and unclear GST
   labelling — fine for ₹800 of small parts, verify before an ₹18k order.
5. Amazon.in MG996R "4-packs" at ₹1,749 are the 360° version. Six correct
   singles from Robocraze cost the same.
6. **Check every converter's INPUT range against 2S (6.4–8.4V).** The obvious
   robu 5V/5A buck (SKU 395957, ₹189) specs **9–24V in** — it can never run
   from this pack, and several hobby "UBECs" state 8V/3S minimums despite 2S
   labels. Both converters in Order 1 are page-verified to accept 2S. (The
   original draft of this BOM had the ₹189 buck AND a 3A LM2596 servo rail —
   both caught and replaced in the 10 Aug audit.)

## Display note (V3 stock vs ours — DSI question CLOSED 10 Aug)

The TARS-AI V3 wiki/BOM lists three display options and **all are 5" DSI**
(1024×600 UeeKKoo, 800×480 Hosyond, 800×480 Waveshare), ribbon-connected to
the Pi — the ₹2,470 5" **HDMI** previously found is the wrong interface for
the V3 chassis. In-stock DSI option: **Waveshare 5" DSI 800×480 IPS touch
(thin/light), ₹3,643 at robu** ([product](https://robu.in/product/waveshare-5inch-dsi-display-800-x-480-ips-thin-and-light-design-touch-display/));
the classic 800×480 model the V3 BOM names is ₹4,049 but out of stock.
Decide before ordering: **stock-V3 build → buy the ₹3,643 DSI panel** (matches
the 800×480 screen bracket; print the matching bracket) and skip the ₹427 SPI
unit (net +₹3,216). **Custom-chassis-first → keep the 2.4" SPI.** The V3 wiki
also confirms stock audio = a Waveshare USB sound card bundled with an 8Ω 5W
speaker — our I2S pair is a deliberate deviation (see docs/research-notes.md).

## Power architecture (do not deviate)

```
7.4V 2S pack ──┬── UBEC-8A @ 6.0V ──► PCA9685 V+ ──► servos
 (via 20A BMS) └── UBEC 5V/5A ──────► Raspberry Pi 5 (GPIO 5V pins
                (grounds common,       or a 5A USB-C pigtail)
                 rails separate)

Charging: 8.4V/2A CC/CV adapter ─► female barrel pigtail ─► pack charge
leads (through the BMS). Never a TP4056.
```

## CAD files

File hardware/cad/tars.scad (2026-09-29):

// ============================================================
// TARS mini — parametric chassis, v0.3.1  (sim-validated architecture)
// ============================================================
// Architecture validated in simulation (simulation/v3_sim.py — the
// crutch-vault gait walks 2.4 cm/s and stays upright at every solver
// setting in --robust; audit 2026-09-29) and matching the community
// TARS-AI V3 / Charlie Diaz mechanism:
//
//   BODY  — central chassis styled as the two middle slabs, one print.
//           Holds Pi 5 (vertical), battery, PCA9685, display, speaker.
//           Its bottom TOUCHES THE GROUND between steps (4mm longer
//           than the legs) — the robot never balances.
//           lift: the axle rides a 35mm vertical slot in the body, so
//           pressing the legs down raises the body by up to 35mm
//   LEGS  — the two outer slabs, each turning on a 608ZZ bearing on the
//           shoulder axle (swing). With the body's slot, each leg has the
//           two degrees of freedom of v3_model.py: lift + swing.
//
// Keep dimensions in sync with simulation/v3_model.py.
// Drawing: hardware/drawing.py -> hardware/tars_drawing.png (same numbers).
// v0.3.1 (2026-09-29): the 35 mm lift slot moved from the legs to the body
//   (in the legs the axle sat at the top of the slot, so a leg could only
//   rise, never press down); legs keep a round axle bore and 608ZZ seat;
//   right leg mirrored, so both bearing seats face the body; servo bays
//   symmetric (the left bay sat in the middle of the body); face panels
//   are 3 rows of (h-40)/3-6 by w-12 as the formula intends (they were
//   turned 90 deg and half a panel low).
// v0.4 TODO: lift crank linkage detail (servo horn + link), lids,
//            wire channels. Wheel mode (4 driven slabs, see
//            simulation/roll_sim.py) is the v2-hardware variant.
// ============================================================

/* ---------- master dimensions (= v3_model.py) ---------- */
slab_w     = 40;    // width of one slab
slab_d     = 55;    // depth (front-to-back)
leg_h      = 240;   // leg slab height
body_extra = 4;     // body is longer -> body carries the robot at rest
body_h     = leg_h + body_extra;
gap        = 2;     // visual gap between slabs
body_w     = 2 * slab_w + gap;   // chassis width (two middle slabs, one print)

axle_from_top = 25; // shoulder axle, below the slab tops
axle_d        = 8;  // 8mm aluminium rod
lift_travel   = 35; // vertical slide range of each leg

foot_r  = 6;        // bottom edge round-over (sim: roll, don't pivot)
chamfer = 4;        // vertical edge chamfer (monolith look)
wall    = 2.4;      // shell wall

/* ---------- COTS parts (check hardware/BOM.md) ---------- */
brg_od = 22; brg_w = 7;             // 608ZZ bearing
servo_l = 40.7; servo_w = 20.1; servo_h = 42.9;  // MG996R + play
pi_w = 56; pi_l = 85; pi_t = 21;    // Pi 5 (mounted vertically)
disp_w = 52; disp_h = 82;           // 2.4" SPI display window w/ margin

/* ---------- derived ---------- */
axle_z  = body_h - axle_from_top - body_extra + body_extra; // = leg pivot height
leg_y   = body_w / 2 + gap + slab_w / 2;
total_w = body_w + 2 * (gap + slab_w);

// "assembly" | "exploded" | "print_body" | "print_leg" | "print_leg_right"
RENDER_MODE = "assembly";

/* ============================================================
   primitives
   ============================================================ */

module chamfered_box(w, d, h, c) {   // chamfered VERTICAL edges
    hull()
        for (x = [-1, 1], y = [-1, 1])
            translate([x * (d/2 - c), y * (w/2 - c), 0])
                cylinder(h = h, r = c, $fn = 32);
}

// cross-section with ROUNDED BOTTOM edges, square top (x-z plane)
module foot_profile(d, h, r) {
    hull() {
        translate([-(d/2 - r), r]) circle(r, $fn = 48);
        translate([ (d/2 - r), r]) circle(r, $fn = 48);
        translate([0, h - 0.5]) square([d, 1], center = true);
    }
}

// slab solid: chamfered verticals AND rounded bottom
module slab_solid(w, d, h) {
    intersection() {
        chamfered_box(w, d, h, chamfer);
        rotate([90, 0, 0])
            linear_extrude(w + 2, center = true)
                foot_profile(d, h, foot_r);
    }
}

module face_panels(w, d, h, rows = 3) {
    ph = (h - 40) / rows - 6;
    for (side = [-1, 1], i = [0 : rows - 1])
        translate([side * (d/2 - 1.2 + 0.01), 0, 15 + ph/2 + i * (ph + 6)])
            rotate([0, side * -90, 0])
                translate([0, 0, -1.2])
                    linear_extrude(1.24)
                        offset(r = 3) offset(r = -3)
                            square([ph, w - 12], center = true);   // x becomes height after the turn
}

/* ============================================================
   BODY — central chassis (one print, twin-slab facade)
   ============================================================ */
module body() {
    difference() {
        slab_solid(body_w, slab_d, body_h);

        // interior cavity (leave the axle zone solid-ish)
        translate([0, 0, wall])
            chamfered_box(body_w - 2*wall, slab_d - 2*wall,
                          body_h - wall - 55, 2);

        // twin-slab illusion: centre grooves front + back
        for (side = [-1, 1])
            translate([side * (slab_d/2 - 0.75), 0, -1])
                cube([1.6, gap, body_h + 2], center = false);

        face_panels(body_w, slab_d, body_h);

        // display window — upper front chest
        translate([-slab_d/2 - 1, -disp_w/2, body_h - 35 - disp_h])
            cube([wall + 2, disp_w, disp_h]);

        // speaker grille — lower front
        for (gy = [-3 : 3], gz = [0 : 2])
            translate([-slab_d/2 - 1, gy * 6, 45 + gz * 6])
                rotate([0, 90, 0]) cylinder(h = wall + 2, d = 3, $fn = 16);

        // the LIFT: the axle rides a 35mm vertical slot straight through the
        // body. At rest the body sits on the ground with the axle at the top
        // of the slot; pressing the legs down raises the body up to 35mm
        hull()
            for (dz = [0, lift_travel])
                translate([0, -body_w/2 - gap - 1, axle_z - dz])
                    rotate([-90, 0, 0])
                        cylinder(h = body_w + 2*gap + 2, d = axle_d + 0.6, $fn = 48);

        // servo bays flanking the axle (2x MG996R per side, lift + swing),
        // one against each inner wall
        for (s = [-1, 1])
            translate([-servo_l/2, s > 0 ? body_w/2 - wall - servo_w : -(body_w/2 - wall), axle_z - servo_h + 8])
                cube([servo_l, servo_w, servo_h]);
    }
}

/* ============================================================
   LEG — outer slab: axle bore + 608ZZ seat (swing); the lift slot is in the body
   ============================================================ */
module leg() {
    difference() {
        slab_solid(slab_w, slab_d, leg_h);
        // hollow lower half (battery bay optional in v2; keeps legs light)
        translate([0, 0, wall])
            chamfered_box(slab_w - 2*wall, slab_d - 2*wall, leg_h/2, 2);
        face_panels(slab_w, slab_d, leg_h);

        // shoulder bore: the leg turns on the axle (the swing)
        translate([0, -slab_w/2 - 1, leg_h - axle_from_top])
            rotate([-90, 0, 0])
                cylinder(h = slab_w + 2, d = axle_d + 0.4, $fn = 48);

        // 608ZZ bearing seat on the inboard face (+y; the right leg is mirrored)
        translate([0, slab_w/2 - brg_w + 0.01, leg_h - axle_from_top])
            rotate([-90, 0, 0])
                cylinder(h = brg_w + 0.5, d = brg_od + 0.3, $fn = 64);
    }
}

/* ============================================================
   assembly / print layouts
   ============================================================ */
module assembly(explode = 0) {
    color("gray") translate([0, 0, 0]) body();
    color("dimgray")
        for (s = [-1, 1])
            translate([0, s * (leg_y + explode * 45), body_extra])
                mirror([0, s > 0 ? 1 : 0, 0]) leg();   // bearing seat faces the body
    color("silver")
        translate([0, -total_w/2 - 5 - explode * 40, axle_z])
            rotate([-90, 0, 0])
                cylinder(h = total_w + 10, d = axle_d, $fn = 48);
}

if (RENDER_MODE == "assembly")   assembly(0);
if (RENDER_MODE == "exploded")   assembly(1);
if (RENDER_MODE == "print_body") rotate([0, -90, 0]) body();  // lies on its back
if (RENDER_MODE == "print_leg")  rotate([0, -90, 0]) leg();                       // left
if (RENDER_MODE == "print_leg_right") rotate([0, -90, 0]) mirror([0, 1, 0]) leg();  // right

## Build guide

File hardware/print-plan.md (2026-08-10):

# Print Plan — TARS-AI V3 chassis via 3D-printing service

No home printer — the chassis is printed by an online service, the same way
the micro-quad frame was done (ZBOTiC order placed and delivered within the
week, 10 Aug 2026; received part matched CAD, press-fit bores printed true).

## STL source (pinned)

- Repo: **github.com/TARS-AI-Community/TARS-AI**, branch **V3**
  (do NOT use `main` — obsolete V1/V2 tooling).
- Pinned at download time: commit **`7593f8c8b63c35e3c07cc98665970fe55cee2c23`**
  (branch head as of 13 Apr 2026, unchanged when checked 10 Aug 2026).
- ~130 pre-oriented STLs; assembly footprint 241.8 × 250.1 × 65.4 mm.
  **Print at 100% — do not rescale**; every fit is dimensioned around COTS
  parts (MG996R pockets, 608ZZ seats, the 5" DSI screen bracket).
- License CC-BY-NC 4.0 — personal build fine; attribution: Charlie Diaz /
  TARS-AI Community / AtomikSpace. Selling prints is not allowed.

## Material split (the one thing to get right in the order)

Diaz's V1 broke its printed drivetrain after ~4 steps — heavy torso, PLA
load parts. So:

| Part class | Material | Walls / infill |
|---|---|---|
| Load parts: legs, lift arms/cranks, servo mounts, axle/bearing blocks, anything the torso's weight passes through | **PETG, black** | 3+ walls, ≥30% infill |
| Cosmetic: torso slabs, facade panels, lids, screen bezel | **PLA, black** | 2–3 walls, 15–20% infill |

Layer 0.2 mm, no rescale, keep the STLs' pre-orientation (they ship
print-ready). If the service balks at a per-part material mapping, order as
two batches (one PETG, one PLA) — sort the STLs into two folders before
upload. The exact part-to-class sort happens at download time against the
V3 assembly wiki.

## Where to order (Delhi, carried over from the quad-frame build)

- **[ZBOTiC](https://zbotic.in/product/online-3d-printing-service/)** —
  incumbent; already delivered our quad frame (upload STL → quote).
- [DWart Industries](https://dwartindustries.com/shop/additive-manufacturing/fdm-3d-printing-services/)
  — ₹199 minimum, good for a small test batch.
- [RoboThings](https://robothings.in/online-3d-printing-service-in-india/) (Delhi/NCR),
  [iamRapid](https://iamrapid.com/3d-printing-services-in-delhi/) (1–2 day Delhi delivery).
- Walk-in: [SOCH3D](https://soch3d.com/3d-printing-service/delhi),
  ElectronifyIndia.

Cost is a **quote at upload** (per-gram rate × ~a robot's worth of plastic +
minimums; get two quotes — at 130 parts the per-gram rate dominates).
Sequencing tip from the quad build: the fit-critical parts arrive before the
servos are needed, so order the print set the same day as the electronics.

## ZBOTiC order (carted 10 Aug 2026, ready for checkout)

The full no-arm build was quoted through ZBOTiC's instant-quote flow
(zbotic.in/3d-print-order/) as **16 cart items, ₹5,199.19 incl. GST, free
shipping**: 58 parts merged into per-material "plate" STLs
(`stl-v3-order/plates/`, generated by translate-only packing that preserves
the STLs' print orientation, all z=0 on the bed):

- 6× **PETG black** plates — every structural part (chassis, leg cases,
  hulls, shafts, servo arms, clips): ₹2,839
- 7× **PLA black** plates — lids (upper lid = TARS-cutout version), screen
  support (Waveshare 800×480), Pi/PCA9685/buck supports, base stand
  (small-printer split format), anti-vibration lid mod: ₹1,886
- 1× **TPU 95A black** — all 3 foot pads: ₹397
- 1× **PLA white** — T/A/R/S letters + 12 dots (lid inlay): ₹30
- leg_spacer (tool): ₹46

Per-item special instructions: "pre-oriented, print as placed, min 3
perimeter walls" + the plate's part list. Build decisions baked in: **no
arms** (leg noarm variants; arm parts printable later), **5" screen lid**
(pairs with the Waveshare 5" DSI panel in the BOM), all three mods
(base stand, letter cutouts, anti-vib lid).

Service constraints learned (for reorders): max in-house FDM build
**250×210×250 mm** (bigger → manual quote); accepts STL/OBJ/3MF/STEP only
(no ZIP despite the widget's claim); FDM rates ₹0.72–0.75/cm³ material +
₹80/hr at 0.2 mm; TPU ₹0.7/cm³; qty discounts 5+/10+/25+/50+ = 5–20%;
"non-manifold" warning on multi-shell plates is cosmetic — slicing works;
min order ₹200, free shipping ≥ ~₹950, ~3-day delivery quoted per item.

## On receipt — check before assembly

1. Servo pockets: an MG996R body (40.7 × 19.7 mm) press-fits without force.
2. 608ZZ bearing seats: 22 mm bearing seats snugly (light tap OK, no gap).
3. Axle/lift slots: 35 mm travel is free over the full stroke.
4. Screen bracket matches the panel actually bought (800×480 DSI vs 2.4" SPI).
5. Layer adhesion on PETG load parts: try to flex a leg by hand — no cracking.

Calibrate servos DURING assembly (preset before pressing horns on — see
docs/research-notes.md), and route arm-servo cables through the torso even
though arms come later.

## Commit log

2026-08-09 TARS mini: personality core, parametric CAD, walking gait simulation
    - software/: Claude-powered TARS personality (humor/honesty settings), CLI chat
    - hardware/cad/tars.scad: parametric 4-slab chassis (OpenSCAD)
    - simulation/: MuJoCo gait sim — walks 51cm/10s via IMU balance + kick gait
    - hardware/BOM.md: parts list based on TARS-AI V3 (India pricing pending)
    - docs/: design decisions + community research notes
    [tars.scad]
2026-08-09 Fix gait sim UX: persistent smooth GUI, balanced sweep, tracking camera
    - GUI now runs until the window is closed (was: auto-closed after run)
    - 60fps display sync + real-time pacing (was: stuttery per-step sync)
    - Camera follows the robot; auto-reset on fall
    - --sweep now searches around the IMU-balanced gait (75/75 upright,
    best 56.7cm/8s) instead of the balance-off path (0/144)
    - GaitController class = exactly what the Pi will run on real hardware
    - --push N for shove-robustness testing
2026-08-09 BOM: live-verified India pricing (10 Aug 2026), two-vendor buy plan
    - robu.in + Robocraze covers ~96% of the build: ~₹29.2k combined
    - Pi 5 8GB ₹19,999 dominates cost; 4GB path saves ₹7.4k
    - Traps documented: robu's MG996R is 360° continuous, TP4056 can't
    charge 2S, servo/Pi rails must be separate
    - Full sourcing report archived in docs/india-sourcing-report.md
2026-08-09 V3 morphology walks in sim; Miller's-planet wheel mode; CAD v0.3
    - v3_model/v3_sim: body-on-ground + lift/swing legs (the build architecture)
    walks 2.3cm/s quasi-static with ZERO falls — no IMU needed. Winning gait:
    feet plant 14deg behind, 30% lift, vault overlapped with lowering.
    - pinwheel_model/roll_sim: 4-slab rimless wheel cartwheels 1.4-1.6m from a
    1.8 m/s kickstart (cannot self-start: 45deg tip-overs — movie-accurate).
    Powered sustained rolling documented as v2 research (TARS3D telescoping).
    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
    [tars.scad]
2026-08-10 Pre-order audit: fix power chain, honest sim torque, brain.py history bug
    Full adversarially-verified audit before ordering parts. Blockers fixed:
    - BOM power chain rebuilt with 2S-verified parts: LM2596 (3A) servo rail
    replaced by UBEC-8A 2-8S @6.0V (Rs.1,579); 9-24V-input Pi buck replaced
    by UBEC 5V/5A SKU 974872 (Rs.392); added the missing 8.4V/2A CC/CV 2S
    charger, 20A BMS, 8-ohm 2W speaker, and PETG spool. New all-in total
    Rs.33,500-33,800 across three orders (robu + Robocraze + ThinkRobotics).
    - Display question closed: TARS-AI V3 wiki lists only 5" DSI panels; the
    Rs.2,470 HDMI find was the wrong interface. In-stock DSI option noted.
    - Sim servo torque corrected 2.5 -> 1.0 N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
2026-08-10 Switch to outsourced 3D printing; add print plan, drop filament spools
    No home printer — chassis parts will be ordered from an online print
    service, the workflow proven the same week on the micro-quad project
    (ZBOTiC order delivered 10 Aug 2026, part matched CAD).
    - hardware/print-plan.md (new): TARS-AI V3 STL source pinned at commit
    7593f8c, black PETG 3+ walls for load parts vs black PLA cosmetic
    (the Diaz V1 drivetrain failure), Delhi service vendor list, print
    settings, and on-receipt fit checks (servo pockets, 608ZZ seats,
    screen bracket).
    - BOM: PLA+/PETG spool lines removed (service supplies material);
    electronics total now ~Rs.31,450-31,750 + printing quote.
    - decisions.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
2026-08-10 Record ZBOTiC print order: 16 plates carted, Rs.5,199 incl. GST
    Full no-arm V3 print set quoted through ZBOTiC's instant-quote flow and
    carted (checkout pending). 58 STLs from the pinned commit merged into
    per-material plate files via translate-only packing (orientation
    preserved, z=0): 6 PETG-black structural plates, 7 PLA-black plates
    (TARS-cutout lid, screen support, electronics supports, small-format
    base stand, anti-vib lid), TPU foot pads, white letter inlays.
    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
2026-09-29 Fall tests check every slab: the IMU walker and wheel mode do not hold up
    gait_sim.py only checked the torso (z > 0.10 m, tilt < 70 deg), so the
    IMU-balance walker reported "stayed upright" while its slabs slumped to
    ~60 deg within 0.5 s (a tilted A-frame, axle at 140 mm instead of 219).
    The test now requires the torso and both slab pairs within 45 deg of
    vertical and the axle above 150 mm: the walker falls (0/75 sweep settings).
    roll_sim.py only checked the hub axis for a sideways roll. Thrown in at
    1.8 m/s the pinwheel tumbles ~0.4 m, folds flat (hub 28 mm up) and creeps
    undriven, which is where "~1.6 m" came from. A hub on the floor now counts
    as a fall; stiffer spokes (5-20 N m) fall si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
2026-09-29 V3 gait: a crutch vault that holds at every solver setting (--robust)
    The old keyframes (feet planted 14 deg ahead, vault overlapped with
    lowering) walked only at MuJoCo's default 2 ms step: at 0.5 ms, with the
    implicitfast integrator or with elliptic friction cones the robot tipped
    over within 3-9 s. The body landed before it vaulted; the progress came
    from rocking on the rails.
    New gait, same model and servos: press down on VERTICAL legs (weight over
    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
    [tars.scad]
2026-09-29 CAD v0.3.1: the lift slot moves to the body; mirrored leg, symmetric bays, panels
    Sections through tars.scad turned up four problems in v0.3:
    - The 35 mm lift slot was in the legs with the axle at its top at rest, so a
    leg could only rise, never press down. The slot is now in the body (axle at
    the top at rest; pressing the legs down raises the body up to 35 mm), the
    relative motion v3_model.py already simulates. Legs keep a round bore and
    a round 608ZZ seat for the swing.
    - The right leg was not mirrored, so its bearing seat faced outwards; both
    now face the body (new print_leg_right mode).
    - The left servo bay sat in the middle of the body; the bays are now mirror
    images, one ag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
    [tars.scad]
